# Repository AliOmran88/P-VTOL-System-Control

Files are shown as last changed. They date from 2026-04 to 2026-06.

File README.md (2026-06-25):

# P-VTOL Control System

A 1-DOF Planar Vertical Take-Off and Landing (P-VTOL) platform developed for studying system modeling, state-feedback control, embedded systems, and real-time communication between Arduino and LabVIEW.

The project demonstrates the complete workflow from mechanical design and fabrication to controller implementation and experimental validation on a physical system.

---

## Project Overview

The objective of this project is to stabilize and control the angular position of a rotating beam actuated by two BLDC motors.

The project is divided into the following stages:

1. Mechanical Design
2. Mathematical Modeling
3. Sensor Measurement and State Estimation
4. State-Feedback Controller Design
5. Arduino Implementation
6. LabVIEW Monitoring and Analysis
7. Real-Time Communication using NI-VISA
8. Experimental Validation

---

# Mechanical Design

The mechanical structure was designed using SolidWorks and fabricated using 3D printing.

Main components include:

* Main Beam
* Motor Holders
* Bearing Supports
* Sensor Mounts
* Bearing Retainers
* Teflon Base Plate
* 6201 Bearings
* Flexible Shaft Coupling

### CAD Model

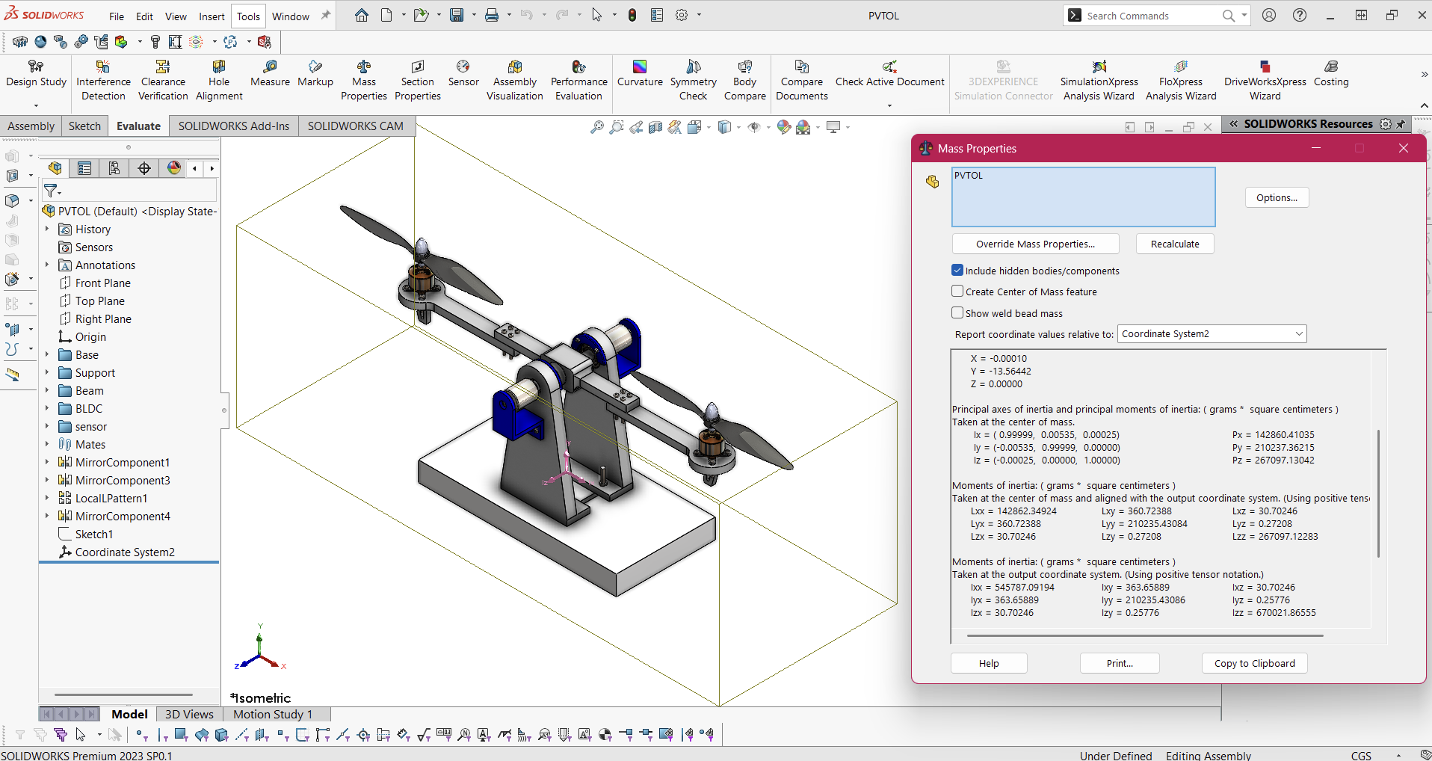
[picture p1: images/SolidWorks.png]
CAD Model


### Final Assembly

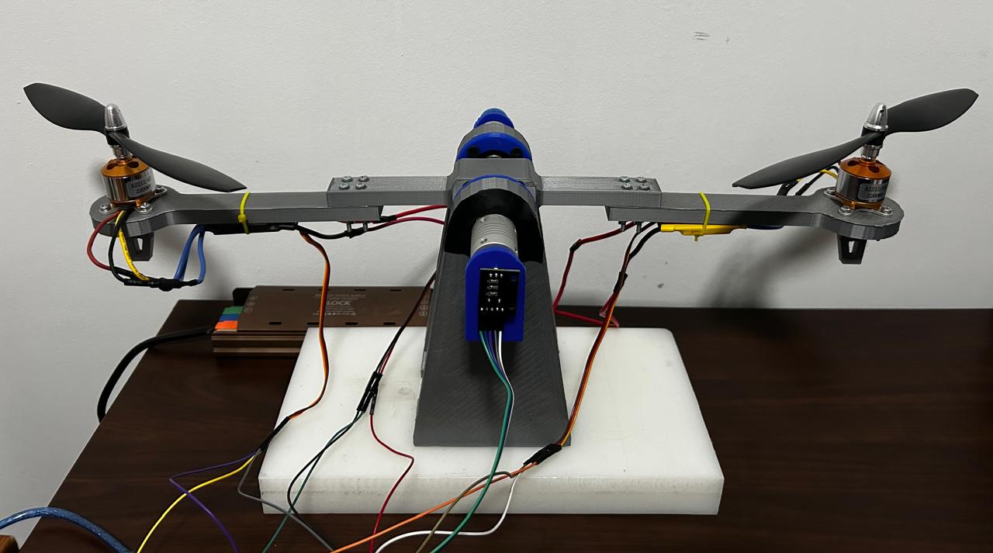
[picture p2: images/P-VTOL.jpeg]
PVTOL System


---

# Mathematical Modeling

The system is modeled as a rigid beam rotating about a fixed pivot.

Differential thrust generated by the two BLDC motors produces the control torque acting on the beam.

The resulting equation of motion is:

```text id="9ktgx0"
Jθ̈ + bθ̇ = u
```

where:

* J : Moment of inertia
* b : Damping coefficient
* θ : Angular position
* u : Control input

The model is converted into state-space form and used for controller design and analysis.

### Free Body Diagram

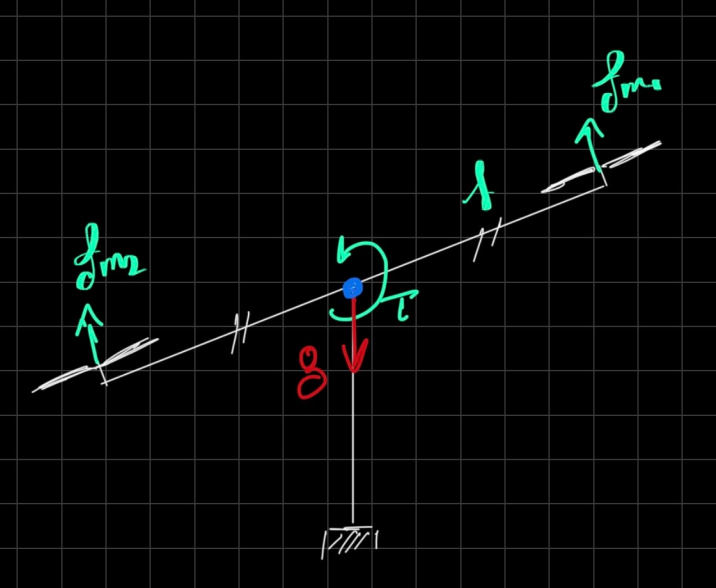
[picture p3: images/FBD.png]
Free Body Diagram


---

# Measurement and State Estimation

An MPU6050 IMU is mounted near the pivot point to estimate the system states.

Measured quantities:

* Angular Position (θ)
* Angular Velocity (ω)

The accelerometer is used to estimate beam angle, while the gyroscope provides angular velocity measurements.

To improve estimation accuracy, a complementary filter is implemented to combine accelerometer and gyroscope measurements.

---

# Control System Design

A state-feedback controller is used to stabilize the system and track reference angles.

The implemented control law is:

```text id="cwsg5z"
du = -(Kθ(θ - θref) + Kωω)
```

where:

* Kθ : Position gain
* Kω : Velocity gain
* θref : Desired angle

The controller uses:

* Angle error for position correction
* Angular velocity feedback for damping

Additional implementation features include:

* PWM Saturation
* Slew-Rate Limiting
* Reference Tracking

### System Block Diagram

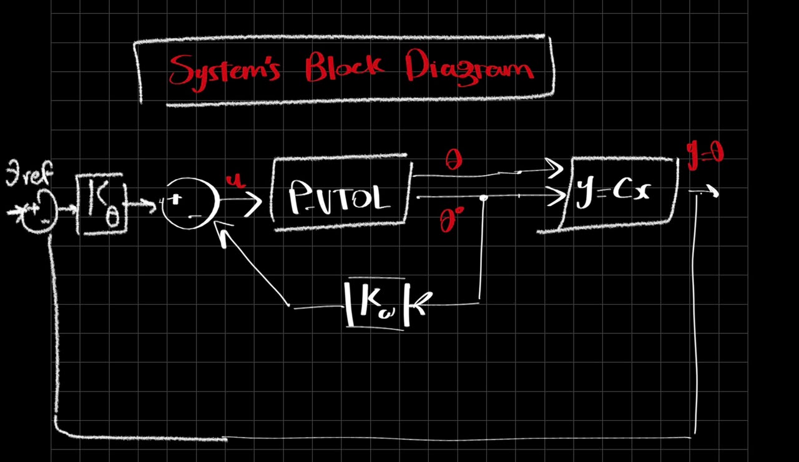
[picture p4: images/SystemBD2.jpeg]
System Block Diagram


---

# Controller Implementation

The complete controller implementation is located inside the **Controller** directory.

```text id="c49h7k"
Controller/
├── RootLocusSF.vi
├── UI_VISA.vi
├── SF_Servo.vi
└── SF_Control/
    └── SF_Control.ino
```

---

## RootLocusSF.vi

This LabVIEW VI was developed for controller design and system analysis.

Functions:

* Enter system parameters
* Construct the state-space model
* Analyze open-loop dynamics
* Calculate state-feedback gains
* Plot root locus
* Compare system response before and after control

This VI was used to determine suitable controller gains before implementing them on the physical system.

### Dynamic Analysis VI

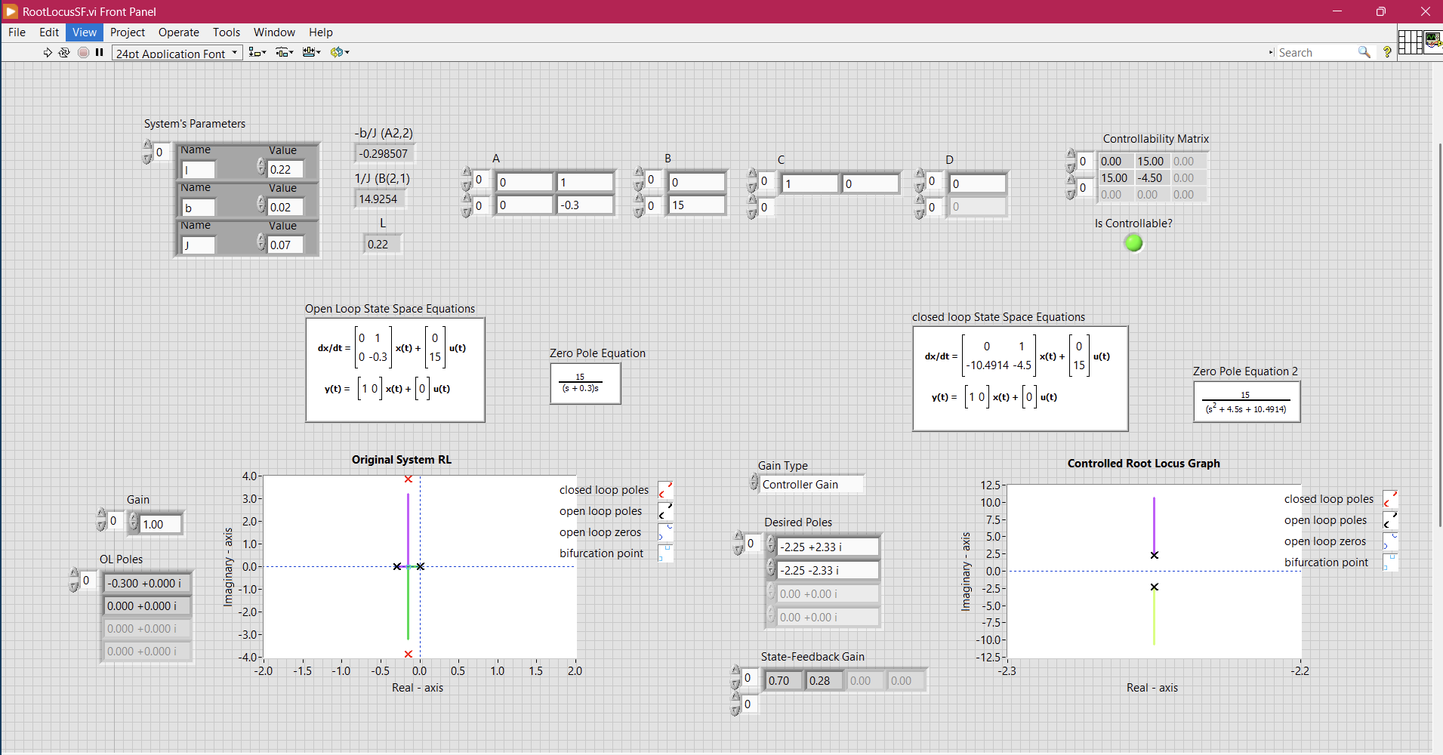
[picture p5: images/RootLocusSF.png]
LabVIEW Analysis


### Access File

[Open RootLocusSF.vi](Controller/RootLocusSF.vi)

---

## SF_Servo.vi

This LabVIEW VI was developed for simulating tracking problem of the system (as it is type 1, with integrator).

### Tracking Problem Simulation VI

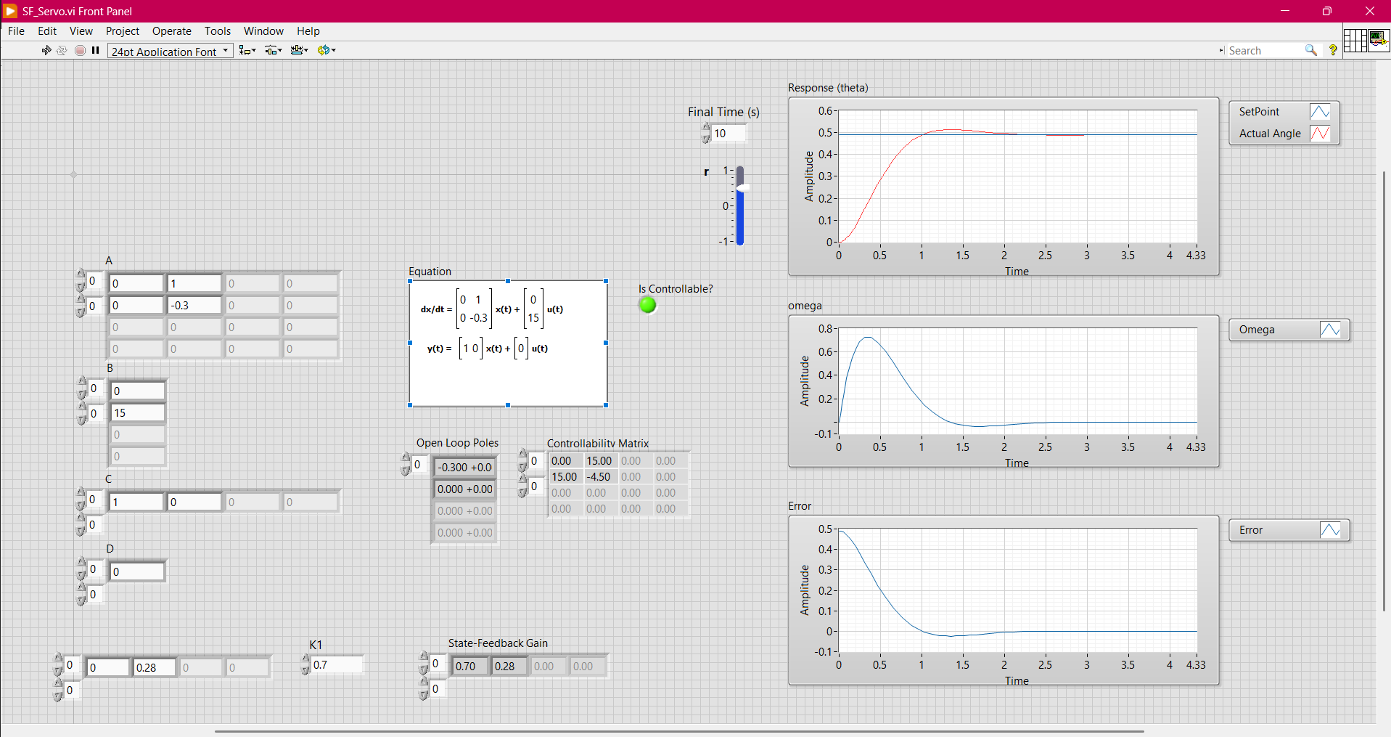
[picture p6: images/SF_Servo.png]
Tracking Simulation

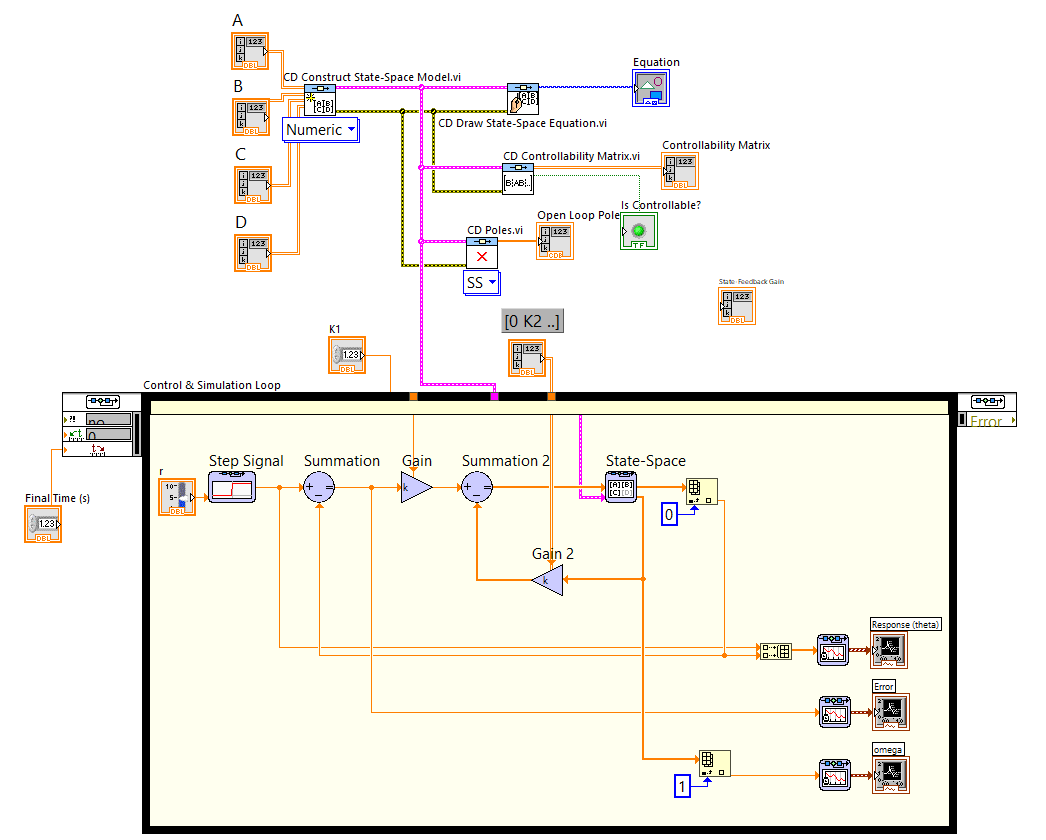
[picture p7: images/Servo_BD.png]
Block Diagram


### Access File

[Open SF_Servo.vi](Controller/SF_Servo.vi)

---

## SF_Control.ino

This Arduino program implements the real-time controller.

Responsibilities:

* Read MPU6050 measurements
* Estimate angle and angular velocity
* Execute the state-feedback control law
* Generate ESC commands
* Apply PWM saturation and slew-rate limiting
* Send measurements and control signals to LabVIEW
* Receive controller gains and reference angle from LabVIEW

The Arduino serves as the embedded controller responsible for executing the control loop in real time.

### Access File

[Open SF_Control.ino](Controller/SF_Control/SF_Control.ino)

---

## UI_VISA.vi

This LabVIEW VI provides the user interface used during experiments.

Functions:

* Send reference angle (θref)
* Send controller gains (Kθ and Kω)
* Receive system measurements
* Receive motor commands
* Plot real-time data
* Monitor system performance
* Tune controller parameters online

This allows controller gains and setpoints to be modified during operation without reprogramming the Arduino.

### User Interface

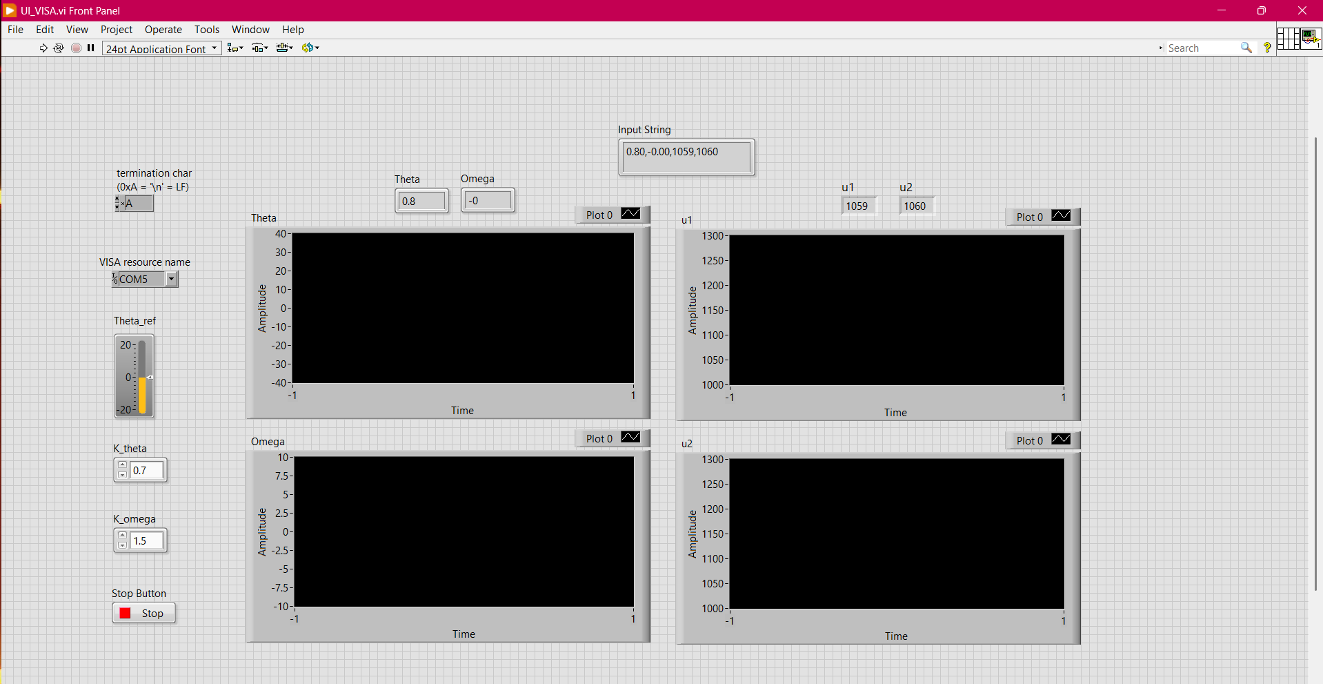
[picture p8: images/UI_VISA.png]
LabVIEW Interface


### Access File

[Open UI_VISA.vi](Controller/UI_VISA.vi)

---

# Serial Communication Using NI-VISA

Communication between Arduino and LabVIEW is achieved through NI-VISA serial communication.

### Data Sent from LabVIEW

* Reference Angle (θref)
* Position Gain (Kθ)
* Velocity Gain (Kω)

### Data Sent from Arduino

* Angular Position (θ)
* Angular Velocity (ω)
* Motor Command u1
* Motor Command u2

This bidirectional communication enables real-time monitoring, controller tuning, and experimental validation.

---

# Experimental Results

The state-feedback controller successfully stabilizes the beam and tracks reference angles in real time.

During operation:

1. LabVIEW sends controller gains and desired setpoints.
2. Arduino executes the control algorithm.
3. Sensor measurements are acquired and processed.
4. Control commands are sent to the motors.
5. System states and actuator commands are streamed back to LabVIEW for visualization and analysis.

The complete experimental demonstration is available below.

### Demonstration Video

[Watch Project Demonstration](Videos/testExp.mp4)

---

# Repository Structure

```text id="t9nqmg"
├── Controller/
│   ├── RootLocusSF.vi
│   ├── UI_VISA.vi
│   └── SF_Control/
│       └── SF_Control.ino
│
├── images/
│
├── Videos/
│
├── CAD/
│
├── STL/
│
├── Docs/
│
└── README.md
```

---

# Future Improvements

Possible extensions of this project include:

* LQR Control
* LQG Control
* Kalman Filtering
* Fuzzy Logic Control
* Model Predictive Control (MPC)
* Vision-Based Feedback
* Adaptive Control

---

# Author

**Ali Gamal Ali**

Mail: 
ali.gamal@ejust.edu.eg

LinkedIn:
https://www.linkedin.com/in/ali-gamal

GitHub:
https://github.com/AliOmran88

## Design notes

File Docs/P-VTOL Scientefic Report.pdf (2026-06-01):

## P-VTOL Control System Project Guide

Ali Gamal Ali

## Introduction

This document serves as a practical guide for students working on the P-VTOL (Planar Vertical Take-Off and Landing) project.

The goal of the project is to design, model, control, and experimentally validate a one degree-offreedom (1-DOF) aerial platform actuated by two brushless DC (BLDC) motors.

## Mechanical Design

The project started with the design of a lightweight structure capable of rotating around a fixed pivot, parts stated below:

| Main beam
| Motor Holder (×2)
| Bearing Supports (×2)
| Sensor Mount (×2)
| Bearing Retainer (×2)
| Base (Material: Teflon, Dimensions: 30 × 15 × 3 cm, Fabrication: CNC Machining)

The CAD model was developed using SolidWorks, as shown in Figure 1.

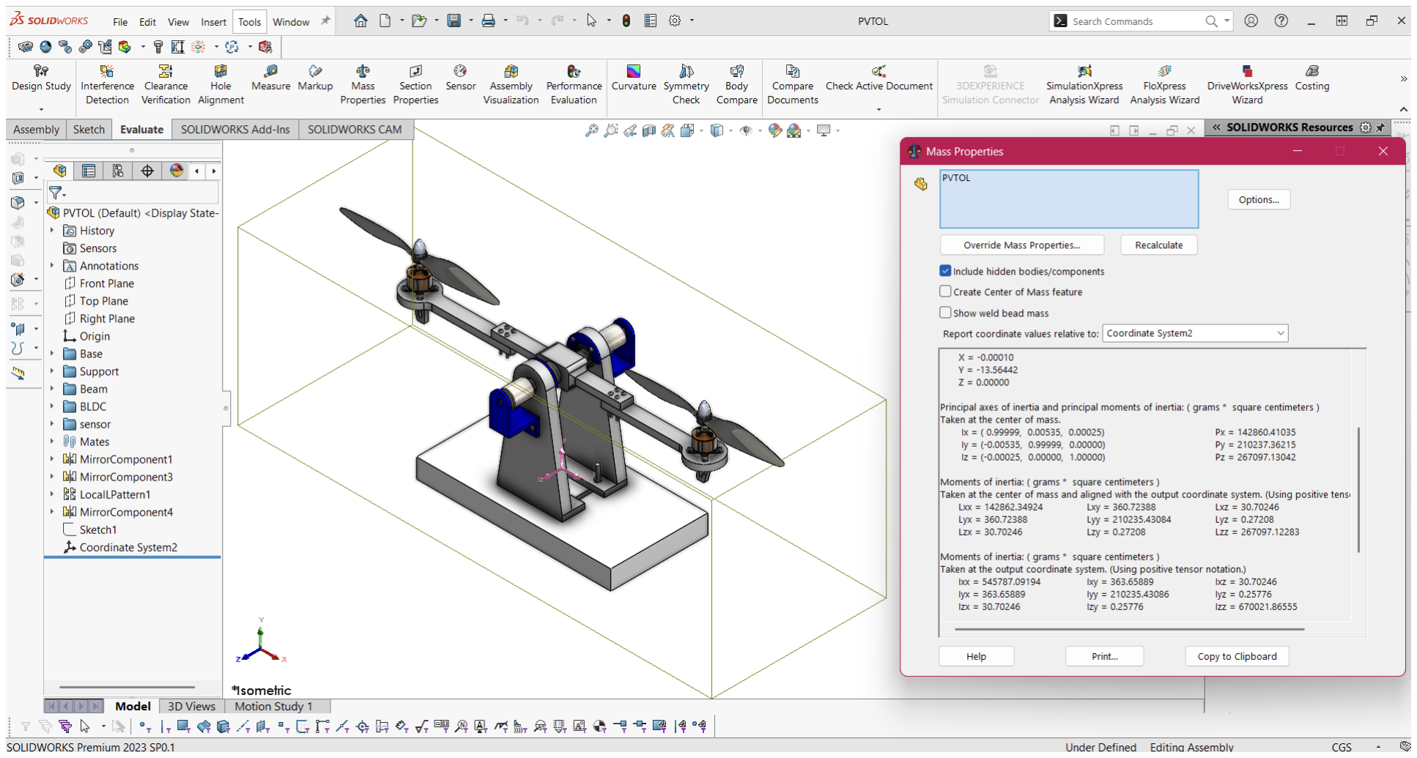
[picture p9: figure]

Figure 1: SolidWorks CAD Assembly Model

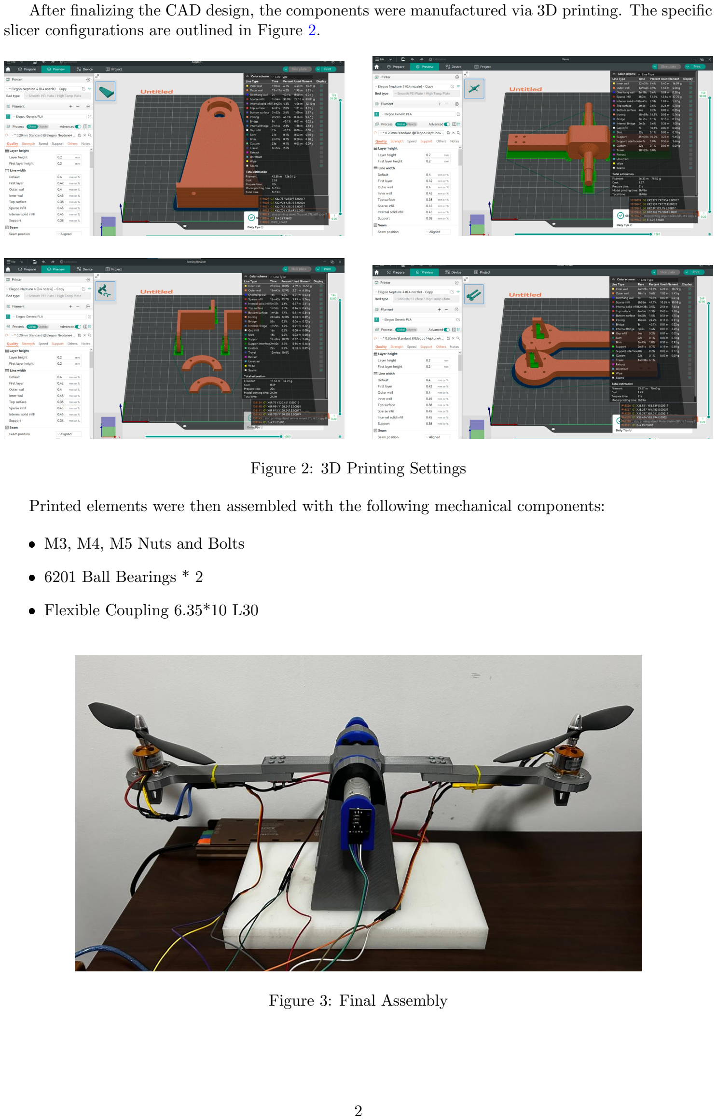
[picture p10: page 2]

After finalizing the CAD design, the components were manufactured via 3D printing. The specific slicer configurations are outlined in Figure 2.

Figure 2: 3D Printing Settings

Printed elements were then assembled with the following mechanical components:

| M3, M4, M5 Nuts and Bolts
| 6201 Ball Bearings * 2
| Flexible Coupling 6.35*10 L30

Figure 3: Final Assembly

## Mathematical Modeling

The P-VTOL platform can be modeled as a rigid beam rotating about a fixed pivot. The angular position of the beam is denoted by θ.

Free Body Diagram

Figure 4 illustrates the free body diagram of the system.


Figure 4: Free body diagram of the P-VTOL system

The control torque is generated by the differential thrust of the two motors,

τ = l(FR − FL)

where l is the distance from the pivot to each motor.
To account for friction and aerodynamic losses, a viscous damping torque is included,

τd = b

˙θ

where b is the damping coefficient.

Euler-Lagrange Formulation

The kinetic energy of the system is

T =

1
2

J ˙θ
2

where J is the moment of inertia about the pivot axis.
Since the beam is balanced around the pivot, the variation in potential energy is negligible,

V = 0

Therefore, the Lagrangian becomes

L = T − V =

1
2

J ˙θ
2

Applying the Euler-Lagrange equation

d

dt
∂L
∂ ˙θ
−

∂L
∂θ = Q

Q = l(FR − FL) − b

˙θ

J ¨θ + b

˙θ = l(FR − FL)

u = l(FR − FL)

the equation of motion becomes

J ¨θ + b

˙θ = u

## State-Space Model

For controller design, the states are chosen as

x1 = θ, x2 = ˙θ

The state equations become

x˙ 1 = x2

x˙ 2 = −

b
J

x2 +

1
J

u

which can be written in matrix form as

x˙ = Ax + Bu

where

A =

"
0 1

0 −

b
J
, B =

"
0
1
J

The output vector is selected as

y = Cx + Du

with

C =

1 0

0 1
, D =
0
0

“‘

## Measurements

The MPU6050 sensor was used to measure angle and angular velocity, The sensor was mounted on top of the beam center near the pivot point.

Angle Measurement

The accelerometer angle (Pitch Angle) was computed using

θacc = tan⁻¹

Ax
Az
∗ 180/π

Ax = g cos θ Az = g sin θ

Schematic for this equation is shown in Figure 5.

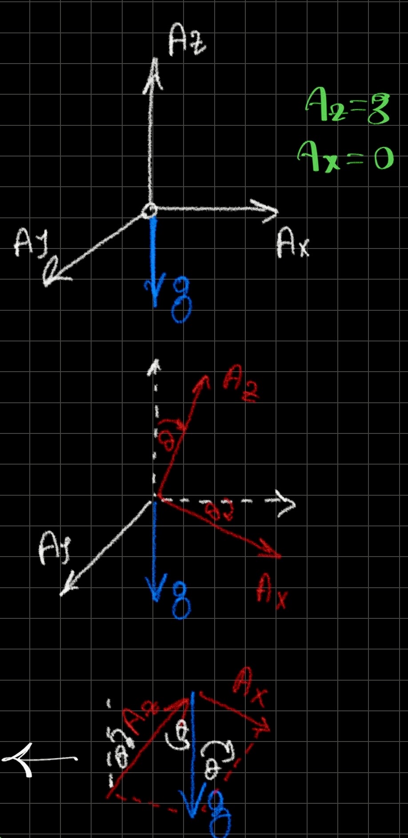
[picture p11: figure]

Figure 5: Obtaining Pitch Angle from Accelerometer

Angle Calibration

Measure angle at startup θref then subtract it as in the equation below, this is to ensure that angle measured is calibrated at zero.

θ = θacc − θref

Angular Velocity Measurement

Angular velocity is defined as the rate of change of angular position over time:

ω =

∆θp
∆t

(rad/s)

For the specific gyroscope sensor used, the sensitivity scale factor is given as 131 LSB = 1◦/s. Therefore, the raw gyroscope reading in the y-axis (Gy) can be converted to degrees per second using:

ωdeg/s =

Gy
131
To ensure measurements are free from zero-rate drift or offset errors, a calibration value (G0 or Goff) must be measured while the sensor is completely at rest. Subtracting this offset yields the corrected angular velocity in degrees per second:

ω =

Gy − G0
131
To convert this corrected measurement into radians per second (rad/s), multiply it by π
180 :

ωrad/s =

Gy − Goff

131
×

π
180

Angle Estimation and Sensor Fusion

Gyroscope Integration

The angular position θ can be measured by integrating the angular velocity ω over a time step dt using Euler’s method:
θi+1 = θi + ω · dt

Complementary Filter

To overcome individual sensor limitations, a complementary filter is implemented. It accounts for the low-frequency drift inherent in gyroscope integration while mitigating the high-frequency noise of the accelerometer data (θacc):
θ = α · (θ + ω · dt) + (1 − α) · θacc

Where α is a tuning constant, typically chosen to be around 0.98.

## System Parameters

The physical parameters of the system are defined as

l = 22 cm = 0.22 m

b = 0.02 N · m · s/rad, J = 0.067 kg · m² (Obtained from SolidWorks)

## State-Space Model

Substituting the system parameters into the state-space equations yields the system matrices

A =

0 1
0 −0.3
, B =
0

15

The output and direct transmission matrices are selected as

C =

1 0

0 1
, D =
0

## Control System Design

The characteristic equation of the system is determined by

Ch. eqn. =⇒ det(sI − A) = 0

Evaluating the determinant of the state matrix gives

s −1
0 s + 0.3

= s(s + 0.3) = 0

Solving for the roots yields the open-loop poles of the system at

s = 0, s = −0.3

## Controllability Analysis

The controllability matrix M is constructed as

M =

B AB
=
0 15

15 −45

Evaluating the rank of the matrix yields

Rank(M) = 2 ”Controllable”

The system is not in controllable canonical form, as second row of B is not 1;

## State-Feedback Control

The state-feedback control law is defined as

u = −Kx = −

K1 K2

x1
x2

Expressing this in terms of physical parameters θ and ˙θ gives

u = −Kθθ − Kω

˙θ

The closed-loop state equation is governed by

x˙ = (A − BK)x

Substituting the state matrix A, input matrix B, and gain vector K yields
0 1
0 −0.3
−
0

15

Kθ Kω

=

0 1
0 −0.3
−
0 | 0
15Kθ | 15Kω

Consequently, the closed-loop system matrix A˜ is obtained as

A˜ =

0 | 1
−15Kθ | −0.3 − 15Kω

## Closed-Loop Pole Placement

The characteristic equation of the closed-loop system is analyzed to determine the closed-loop poles

det(sI − A˜) = 0

Substituting the identity matrix I and the closed-loop system matrix A˜ gives

s 0
0 s
−
0 | 1
−15Kθ | −0.3 − 15Kω

= 0

Simplifying the matrix subtraction within the determinant yields

s | −1
15Kθ | s + 0.3 + 15Kω

= 0

Computing the determinant results in the following polynomial expression

s(s + 0.3 + 15Kω) + 15Kθ = 0

Expanding and grouping the terms by powers of s yields

s

2 + 0.3s + 15Kωs + 15Kθ = 0

s

2 + (0.3 + 15Kω)s + 15Kθ = 0

## Controller Gain Calculation

The actual closed-loop characteristic equation is compared against the standard second-order system design template

s

2 + 2ζωns + ω

2
n = 0

The desired transient performance characteristics are specified as

ζ = 0.7, ωn = 3.24

These parameters correspond to the desired closed-loop pole locations at

s1,2 = −2.25 ± 2.33i

Equating the coefficients of the standard equation to the system’s characteristic equation yields the design formulas

2ζωn = 0.3 + 15Kω

ω

2
n = 15Kθ

Solving this system of equations for the state-feedback gains gives

Kθ = 0.7, Kω = 0.2824

## Experimental Tuning

While the analytical design gives precise theoretical values, physical constraints or unmodeled dynamics often require empirical adjustment.
Comparing the calculated gains against experimental testing yields
Kθ = 0.7, | Kω = 0.2824
Experimentally, Kθ = 0.7, | Kω = 1.5 =⇒ Best Response

## Implementation of the Control Law

Regulator Implementation

For regulation tasks where the primary goal is to drive the system states to zero (θ = 0), the implementation of the state-feedback control law is given by

State-Feedback Control Law =⇒ u = −0.7θ − 0.2824 ˙θ

Regulator: θ = 0

Tracking Implementation

To extend the controller for reference tracking applications, the control law is adjusted to operate on the tracking error vector by comparing the actual states to the desired reference angle

For Tracking =⇒ u = −

Kθ Kω

θ − θref
˙θ

where the reference is set as desired

## Actuation

Differential Control

The base throttle value is established at a baseline level, with differential control applied symmetrically to the actuators:

Base Throttle =⇒ u0 = 1100

u1 = u0 + du

u2 = u0 − du

Slew-Rate Limiting

To preserve actuator longevity and system stability, the change in the pulse-width modulation (PWM) signal per execution step is bounded:

|∆PWM| ≤ Max. allowed Step

where ∆PWM represents the changes ∆u1 and ∆u2. This functions as a:

Limiting Step to avoid sudden spikes in PWM

Saturation

The final control output commands are hard-clipped within physical operating limits:

Saturation Boundary =⇒ [1000, 1300]

State-Feedback Integration

The differential control effort du is derived via the state-feedback tracking law, balancing correction and physical damping:

du = − (Kθ × (θ − θref) + Kω × xω)

where the component terms are allocated to specific control actions:

Kθ × (θ − θref) =⇒ Corrects angle

Kω × xω =⇒ Damps motion

System’s Block Diagram

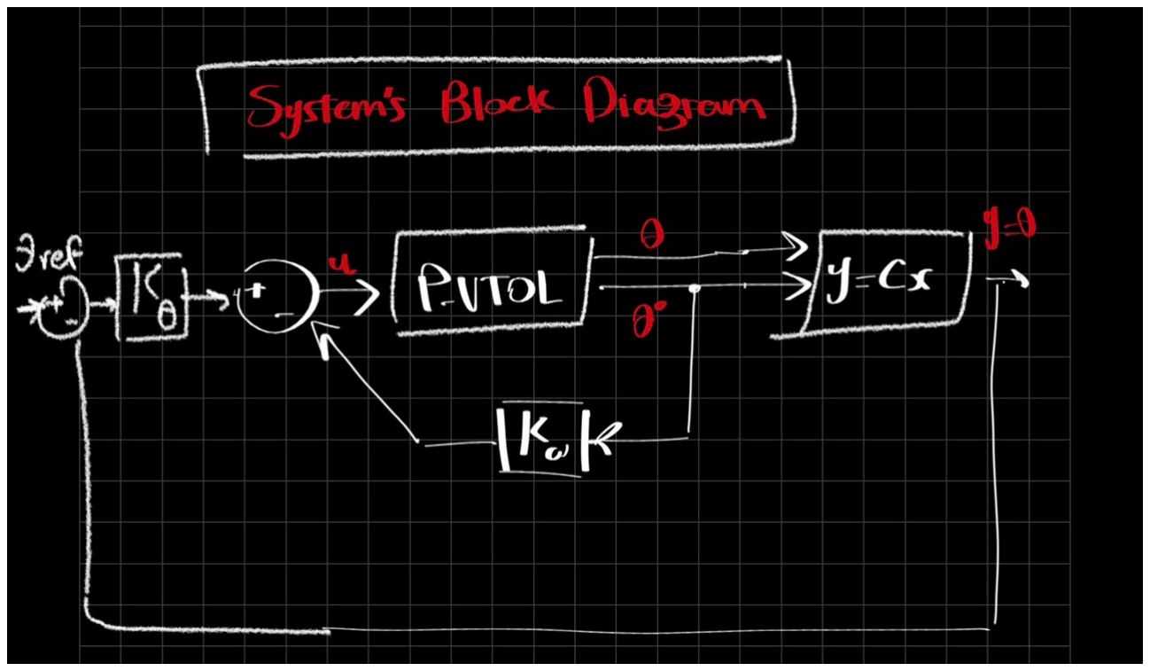
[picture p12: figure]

Figure 6: System’s Block Diagram

## labView Control Design

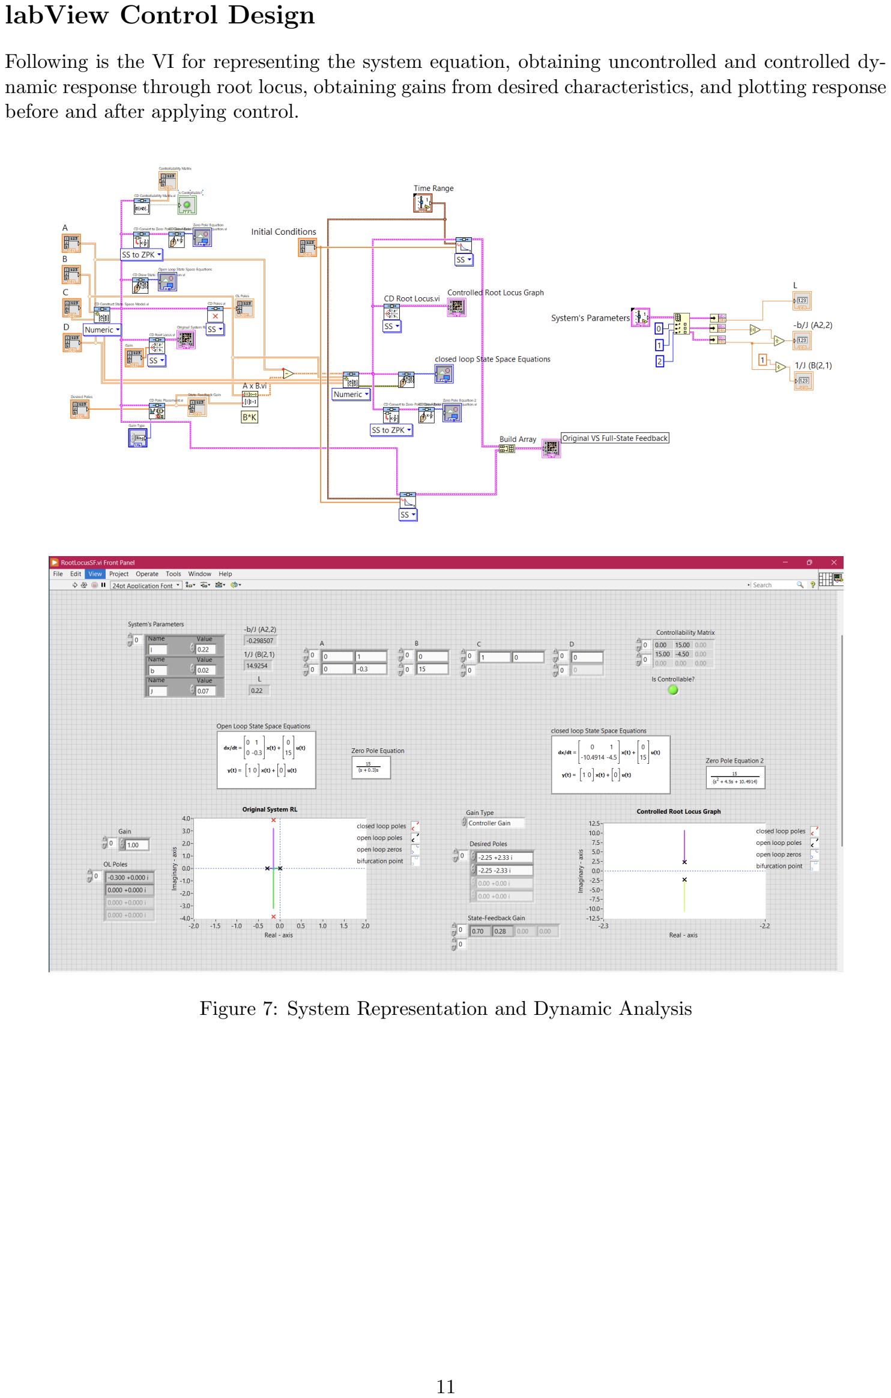
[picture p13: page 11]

Following is the VI for representing the system equation, obtaining uncontrolled and controlled dynamic response through root locus, obtaining gains from desired characteristics, and plotting response before and after applying control.

Figure 7: System Representation and Dynamic Analysis

## Data Acquisition and Communication Interface

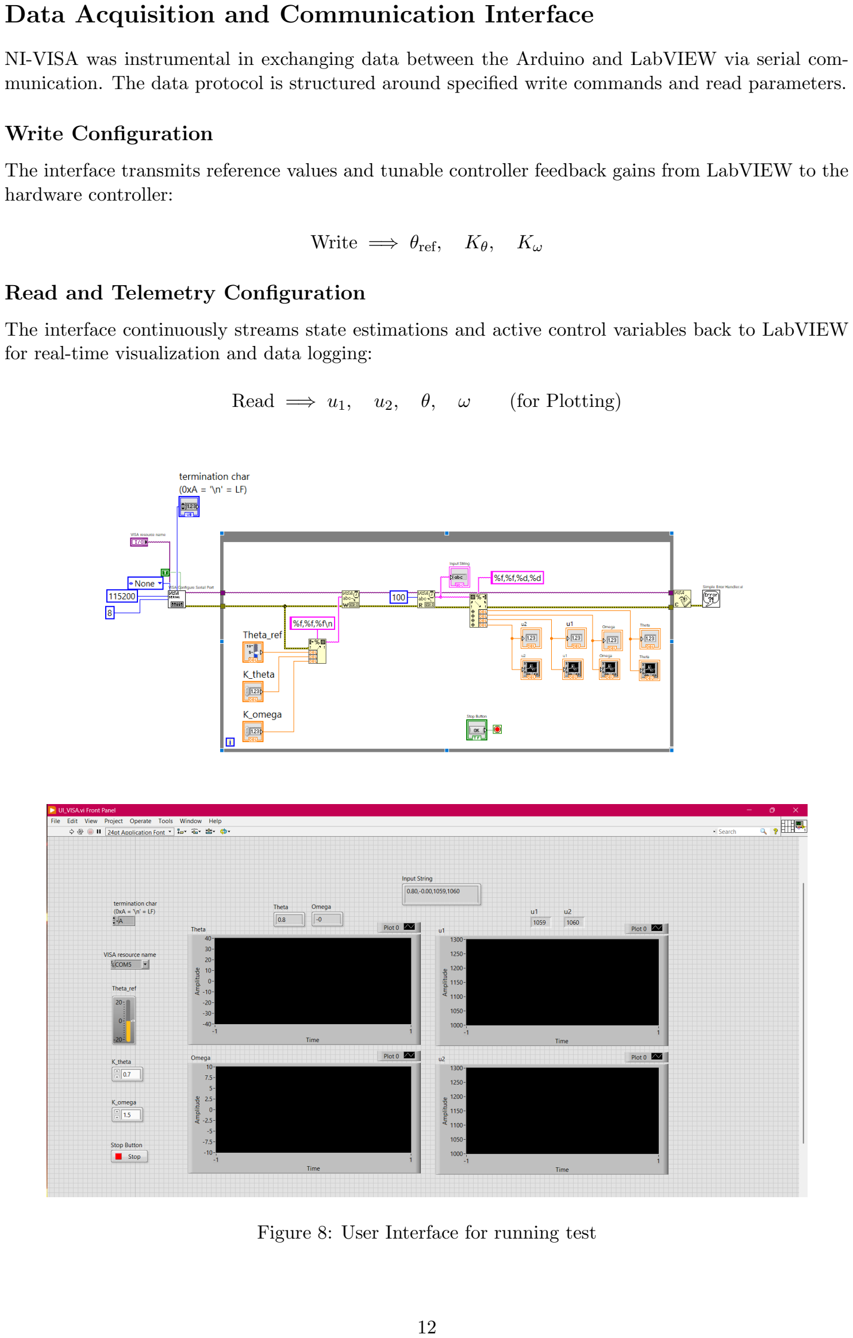
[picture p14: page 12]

NI-VISA was instrumental in exchanging data between the Arduino and LabVIEW via serial communication. The data protocol is structured around specified write commands and read parameters.

Write Configuration

The interface transmits reference values and tunable controller feedback gains from LabVIEW to the hardware controller:

Write =⇒ θref, | Kθ, | Kω

Read and Telemetry Configuration

The interface continuously streams state estimations and active control variables back to LabVIEW for real-time visualization and data logging:

Read =⇒ u1, | u2, | θ, | ω | (for Plotting)

Figure 8: User Interface for running test

## Experimental Results

After completing the implementation, we conducted several experiments to test the system. The state-feedback controller successfully stabilized the beam and held it at the desired equilibrium position. During the tests, LabVIEW and the Arduino worked together in real time. LabVIEW sent the target angles and controller gains down to the Arduino. The Arduino then processed the sensor measurements, ran the control loop, adjusted the motors, and streamed the updated states and actuator efforts back to LabVIEW. This continuous data loop ran smoothly until a stop was requested. The successful balancing performance and real-time tracking are fully captured in the attached experiment video. running experiment video

## Conclusion and Future Work

This project demonstrated the complete development of a P-VTOL control system starting from mechanical design and ending with real-time implementation.
Future students can extend this work by implementing:
| LQR and LQG control
| Kalman filtering for more accurate measurements
| Fuzzy Logic Control
| Model Predictive Control

## References

| “PVTOL Exact Linearization Control,” IEEE Transactions on Automatic Control, for under- lying plant modeling mechanics.
| “Arduino-Based Embedded Systems Interfacing, Simulation, and LabVIEW GUI,” for structural insights regarding VISA buffer configurations.
| “MPU-6050 6-Axis Accelerometer/Gyroscope Datasheet,” InvenSense Inc., detailing calibration constants and LSB scaling ratios.
| “1-DOF Helicopter Stabilization Project Template Guide,” Acknowledgable work done by a colleague, preceding semester.

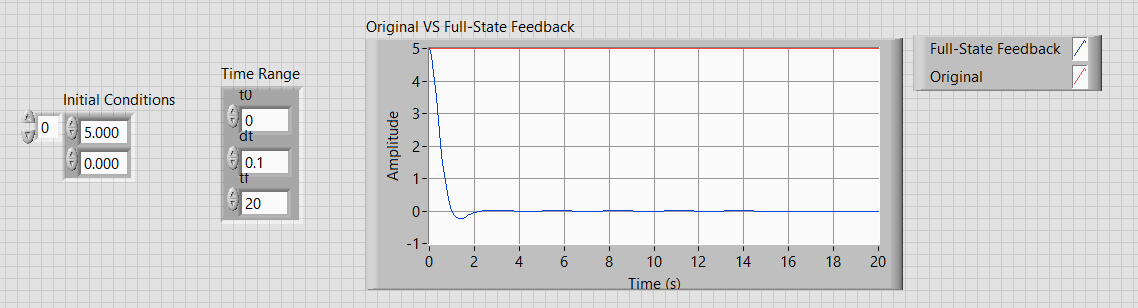
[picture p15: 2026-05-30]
images/RootLocusSF_Response.png

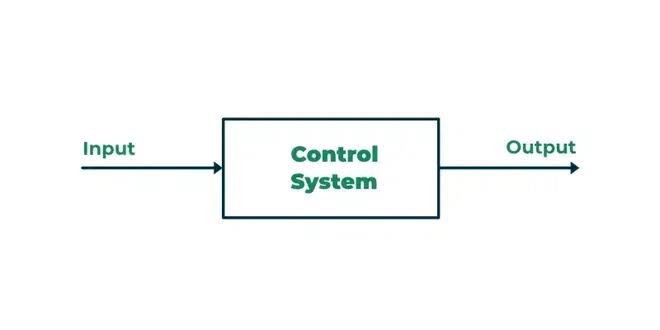
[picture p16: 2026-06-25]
images/cont.jpeg

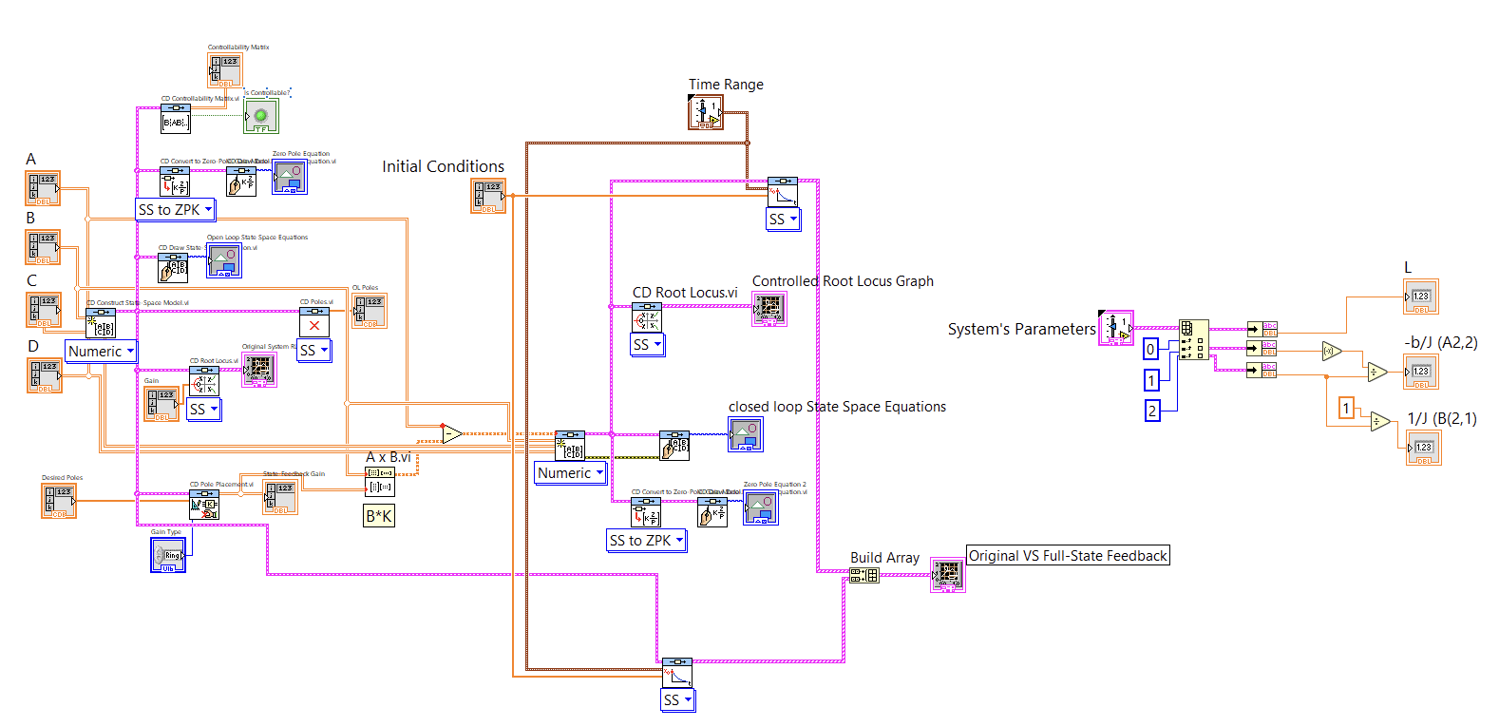
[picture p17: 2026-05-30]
images/RootLocusSF_BlockDiagram.png

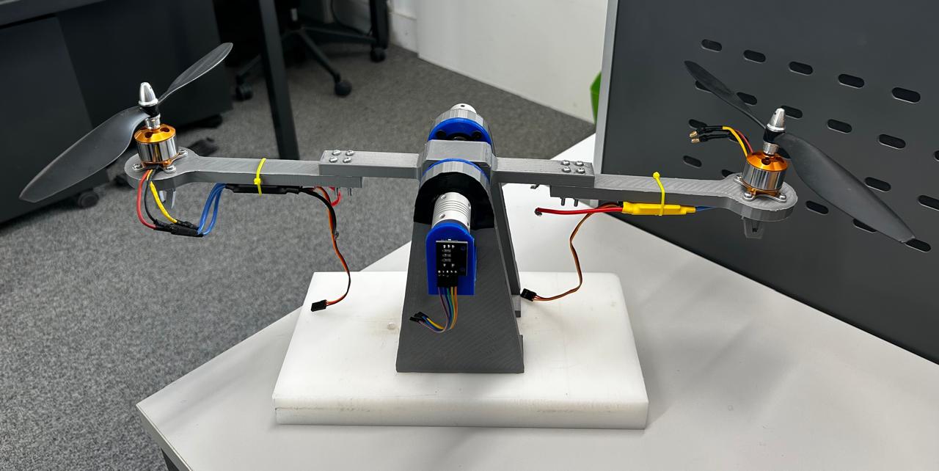
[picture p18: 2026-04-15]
images/PVTOL.jpeg

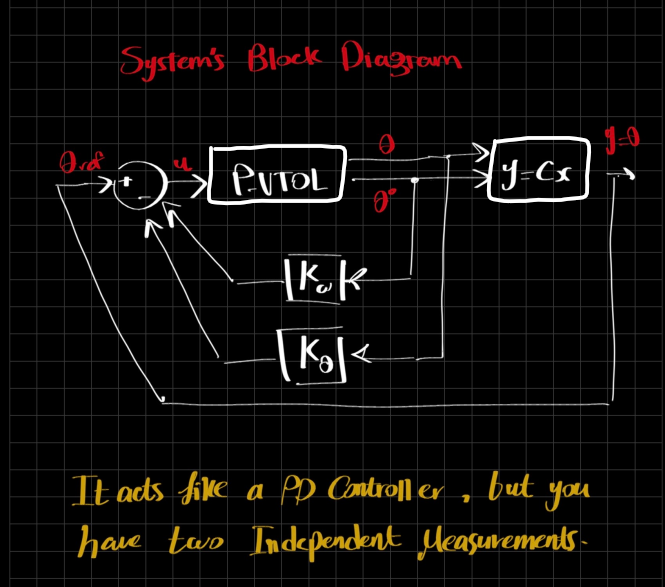
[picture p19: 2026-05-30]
images/SystemBD.png

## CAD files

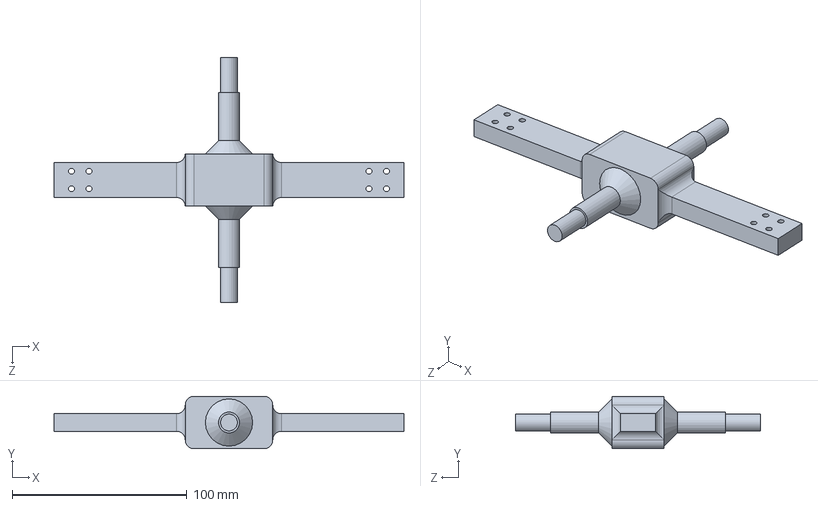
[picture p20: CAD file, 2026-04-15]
CAD/Beam.SLDPRT
200.0 x 30.0 x 140.0 mm

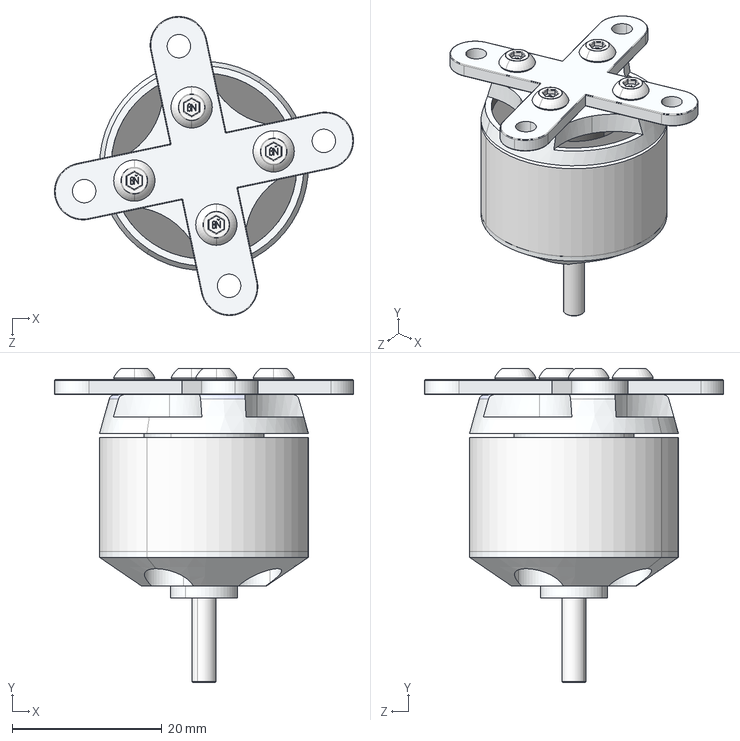
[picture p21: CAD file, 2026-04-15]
CAD/brushless-motor-bldc_2212-6t-2200kv-1.snapshot.1/Motor_BLDC_2212,6T_2200KV__With_Support.STEP
39.9 x 41.9 x 39.9 mm

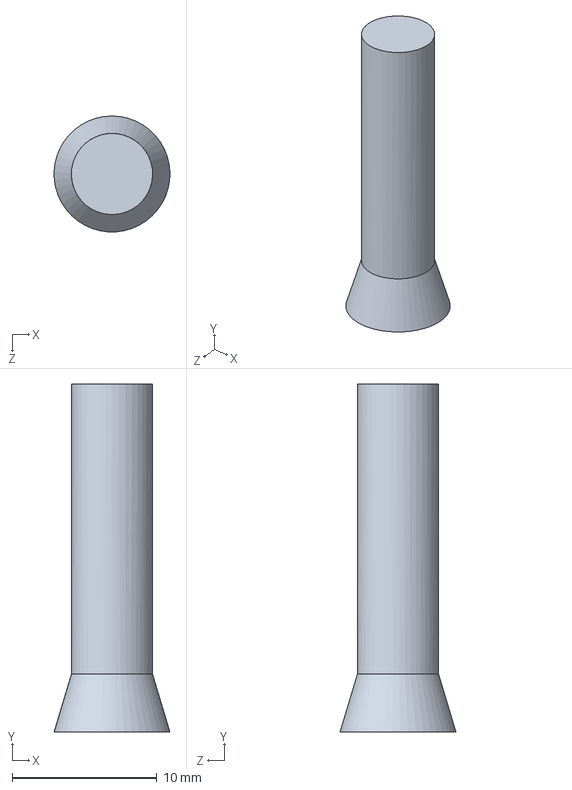
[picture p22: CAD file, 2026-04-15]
CAD/Propeller 10x45/1.SLDPRT
8.00 x 24.0 x 8.00 mm

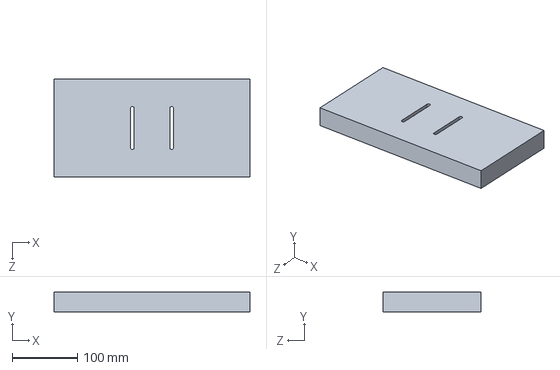
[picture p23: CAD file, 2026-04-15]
CAD/BasePlate.SLDPRT
300.0 x 30.0 x 150.0 mm

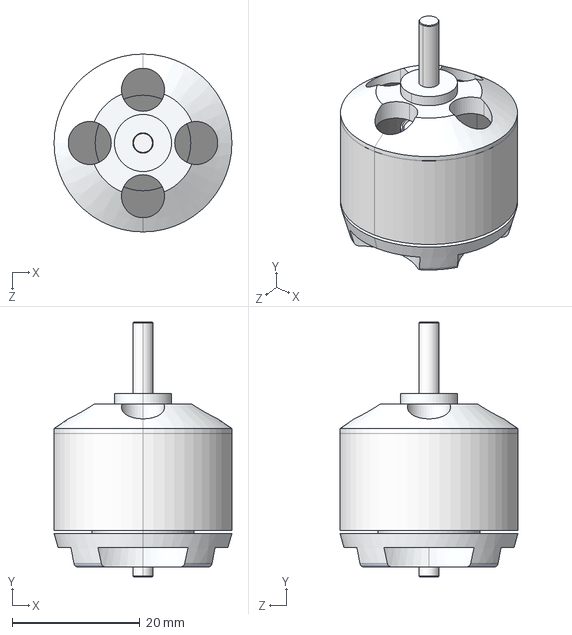
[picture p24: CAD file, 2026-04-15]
CAD/brushless-motor-bldc_2212-6t-2200kv-1.snapshot.1/Motor_BLDC_2212,6T_2200KV.STEP
27.9 x 40.0 x 27.9 mm

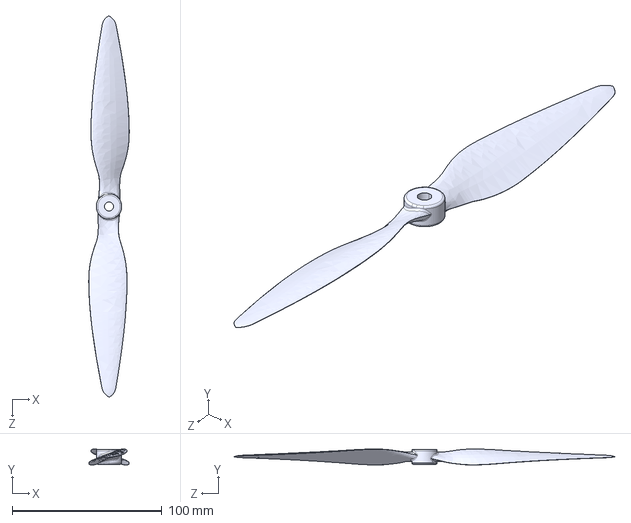
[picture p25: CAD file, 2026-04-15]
CAD/Propeller 10x45/Propeller 10x45.STEP
27.0 x 10.6 x 254.0 mm

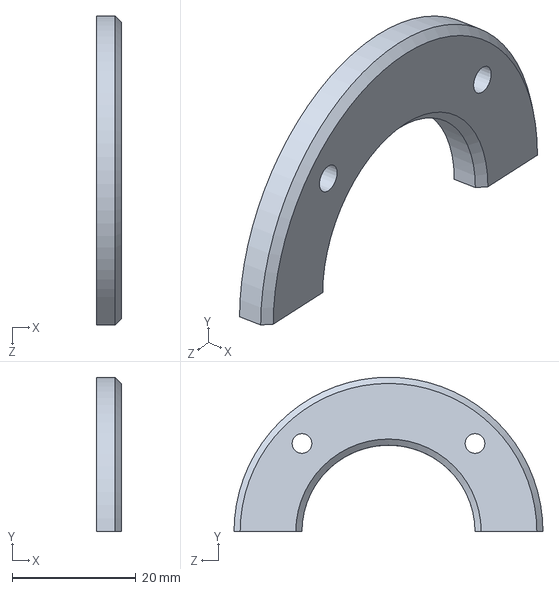
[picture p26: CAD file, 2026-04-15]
CAD/Bearing Retainer.SLDPRT
4.00 x 25.0 x 50.0 mm

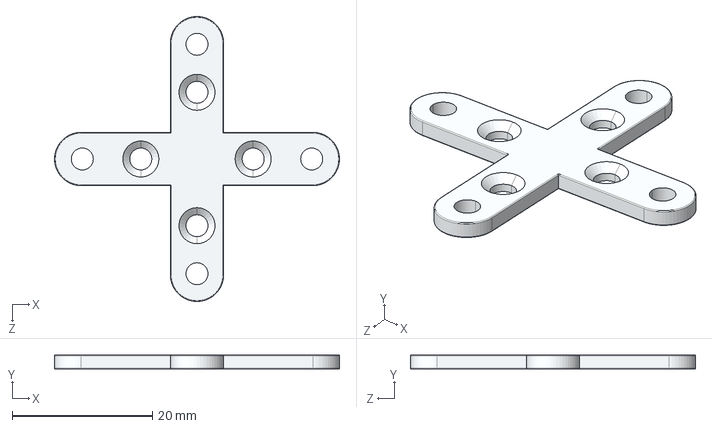
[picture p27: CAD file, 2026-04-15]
CAD/brushless-motor-bldc_2212-6t-2200kv-1.snapshot.1/Support_2MM_Al6061_2212.STEP
40.6 x 2.00 x 40.6 mm

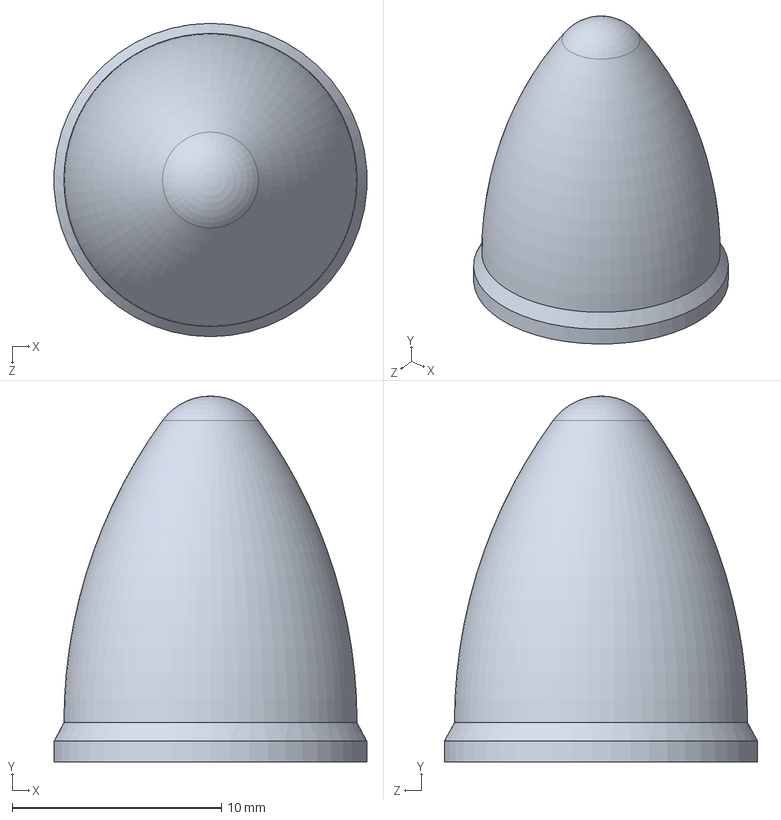
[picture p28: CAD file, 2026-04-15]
CAD/Propeller 10x45/2.SLDPRT
14.9 x 17.5 x 15.0 mm

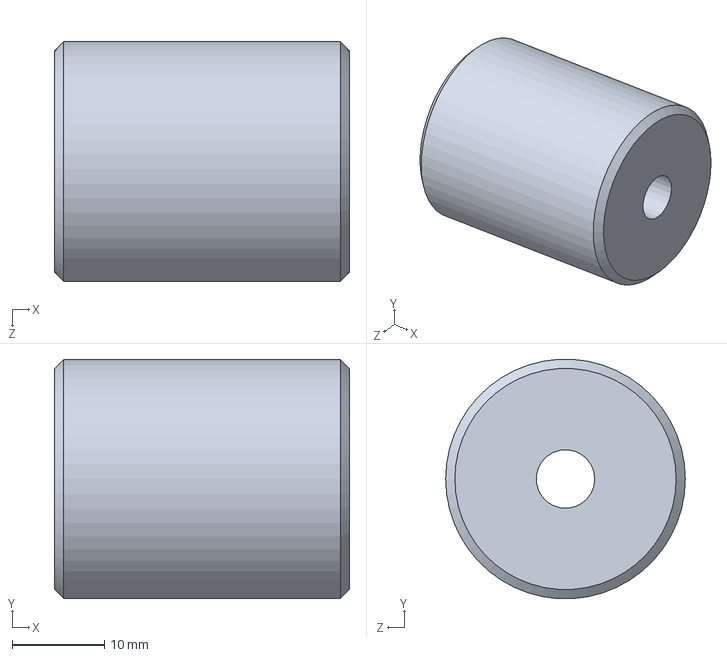
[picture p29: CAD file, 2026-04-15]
CAD/coupler.SLDPRT
32.0 x 25.9 x 26.0 mm

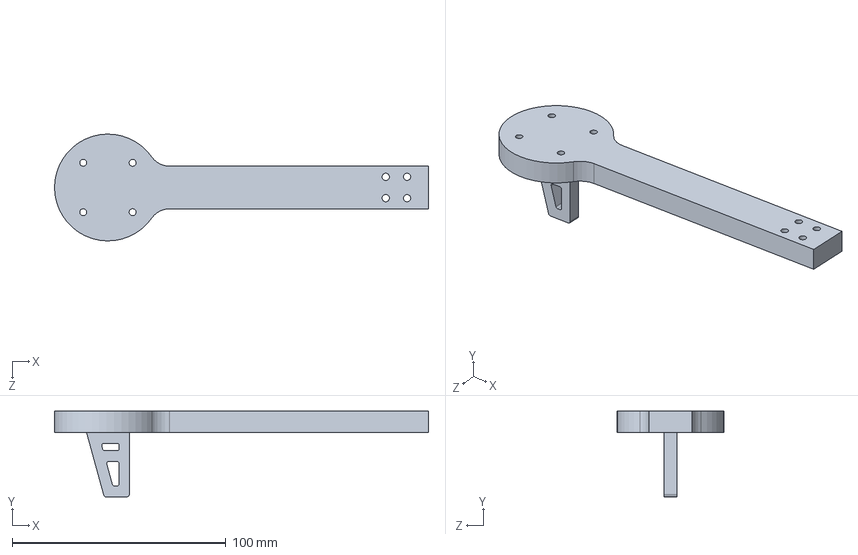
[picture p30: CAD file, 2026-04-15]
CAD/Motor Holder.SLDPRT
175.0 x 40.0 x 50.0 mm

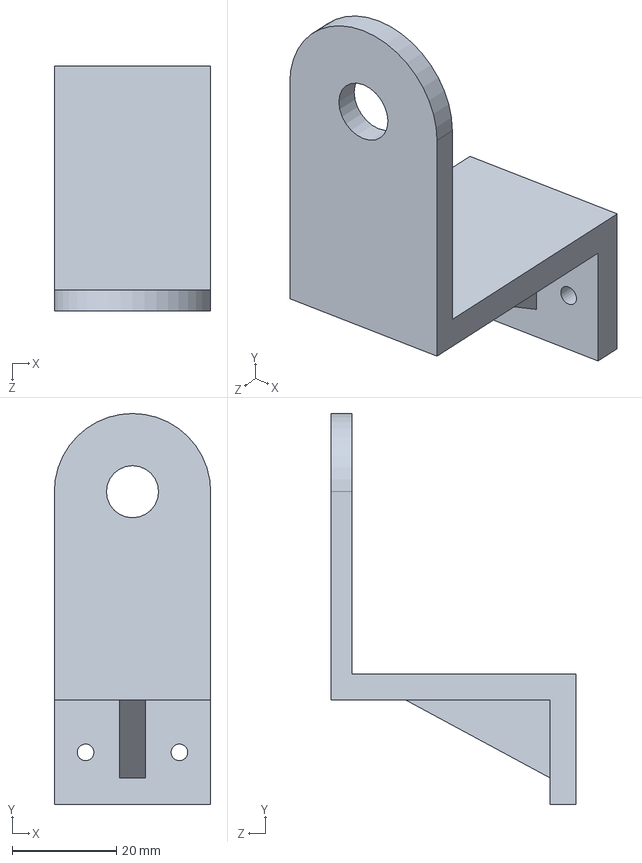
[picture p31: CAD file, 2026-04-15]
CAD/sensor mount.SLDPRT
30.0 x 75.0 x 47.0 mm

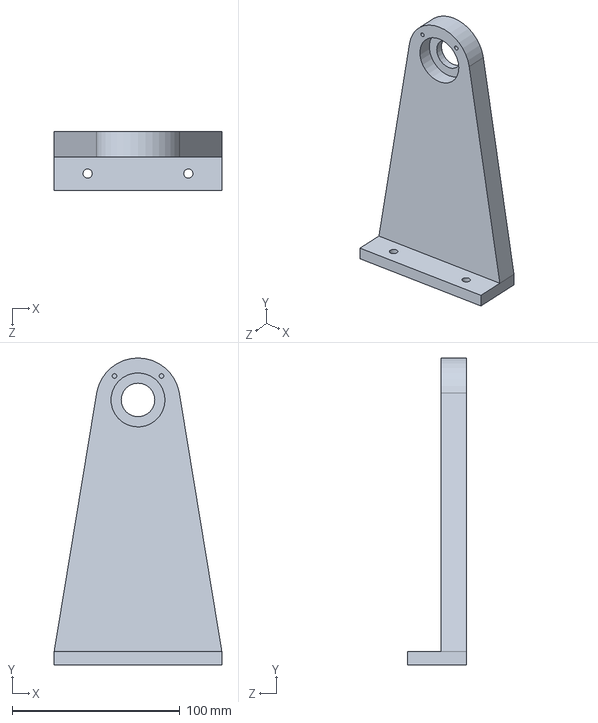
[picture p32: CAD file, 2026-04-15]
CAD/Support.SLDPRT
100.0 x 183.0 x 35.0 mm

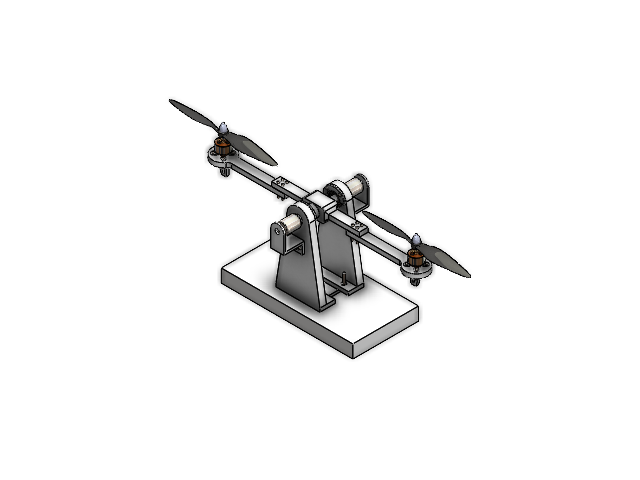
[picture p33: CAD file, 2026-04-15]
CAD/PVTOL.SLDASM
BasePlate
pan cross head_am x 20
hex nut jam_am x 4
Support x 2
Bearing Retainer x 2
radial ball bearing_68_din x 2
pan head tapping screw_am x 8
Beam
Motor Holder x 2
hex nut style 1_am x 16
Motor_BLDC_2212,6T_2200KV x 2
Support_2MM_Al6061_2212 x 2
Propeller 10x45 x 2
coupler x 2
sensor mount x 2

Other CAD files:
CAD/Propeller 10x45/Propeller 10x45.SLDPRT
CAD/basePlateDrw.SLDDRW
CAD/brushless-motor-bldc_2212-6t-2200kv-1.snapshot.1/Motor_BLDC_2212,6T_2200KV.IGS
CAD/brushless-motor-bldc_2212-6t-2200kv-1.snapshot.1/Motor_BLDC_2212,6T_2200KV.SLDPRT
CAD/brushless-motor-bldc_2212-6t-2200kv-1.snapshot.1/Motor_BLDC_2212,6T_2200KV__With_Support.IGS
CAD/brushless-motor-bldc_2212-6t-2200kv-1.snapshot.1/Motor_BLDC_2212,6T_2200KV__With_Support.SLDPRT
CAD/brushless-motor-bldc_2212-6t-2200kv-1.snapshot.1/Motor_BLDC_2212,6T_2200KV__With_Support_.SLDASM
CAD/brushless-motor-bldc_2212-6t-2200kv-1.snapshot.1/Support_2MM_Al6061_2212.IGS
CAD/brushless-motor-bldc_2212-6t-2200kv-1.snapshot.1/Support_2MM_Al6061_2212.SLDPRT
STL/Beam.STL
STL/Bearing Retainer.STL
STL/Motor Holder.STL
STL/Support.STL
STL/sensor mount.STL

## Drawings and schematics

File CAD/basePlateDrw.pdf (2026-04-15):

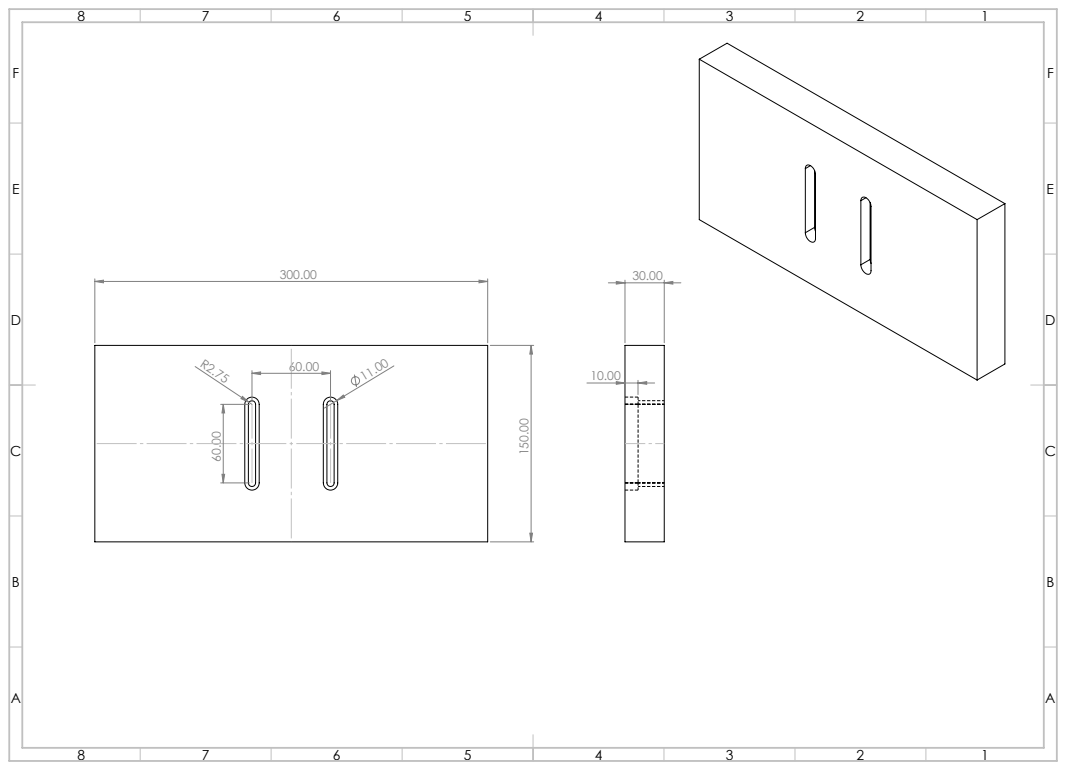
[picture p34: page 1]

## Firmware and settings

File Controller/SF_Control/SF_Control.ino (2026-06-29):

#include <Servo.h>
#include <Wire.h>
#include <avr/wdt.h>

// MPU6050
const int MPU_addr = 0x68;

int16_t AcX, AcY, AcZ, GyY;

// Angle and Angular Velocity
float theta = 0.0;        // filtered angle [deg]
float theta_acc = 0.0;    // accelerometer angle [deg]

float omega_deg = 0.0;    // gyro velocity [deg/s]
float omega = 0.0;        // gyro velocity [rad/s]

// Calibration offsets
float baseY = 0.0;
float gyroY_offset = 0.0;

// Complementary filter coefficient
float alpha = 0.99;

// Motors
const int motor1Pin = 9;
const int motor2Pin = 10;

Servo motor1;
Servo motor2;

// Timing
unsigned long lastTime = 0;
const unsigned long Ts_ms = 20;

// State Feedback Parameters
float theta_ref = 0;
float K_theta = 0.4;
float K_omega = 0.8;

// ESC Parameters

int u0 = 1100;

int u_min = 1000;
int u_max = 1300;

float pwm_slew = 6.0;
float u1_prev = 1000;
float u2_prev = 1000;

// Read MPU6050 using I2C

void readMPU()
{
  Wire.beginTransmission(MPU_addr);
  // Start reading from ACCEL_XOUT_H register
  Wire.write(0x3B);
  Wire.endTransmission(false);
  // Request 14 bytes
  Wire.requestFrom(MPU_addr, 14, true);
  // Accelerometer
  AcX = Wire.read() << 8 | Wire.read();
  AcY = Wire.read() << 8 | Wire.read();
  AcZ = Wire.read() << 8 | Wire.read();
  // Skip temperature
  Wire.read();
  Wire.read();
  // Skip GyX
  Wire.read();
  Wire.read();
  // Read GyY
  GyY = Wire.read() << 8 | Wire.read();
  // GyZ discarded automatically
}

void readSerialData()
{
  char buffer[32];

  if (Serial.available() > 0)
  {
    int len = Serial.readBytesUntil('\n',
                                    buffer,
                                    sizeof(buffer) - 1);

    buffer[len] = '\0';

    float ref, kp, kd;

    int parsed = sscanf(buffer,
                        "%f,%f,%f",
                        &ref,
                        &kp,
                        &kd);

    // Make sure ALL values received correctly
    if (parsed == 3)
    {
      // Safety limits
      if (ref >= -40.0 && ref <= 40.0)
      {
        theta_ref = ref;
      }

      if (kp >= 0.0 && kp <= 20.0)
      {
        K_theta = kp;
      }

      if (kd >= 0.0 && kd <= 20.0)
      {
        K_omega = kd;
      }
    }
  }
}

void readSerialDat()
{
    if (Serial.available() > 0)
    {
        String input = Serial.readStringUntil('\n');

        input.trim();

        // Find commas
        int firstComma  = input.indexOf(',');
        int secondComma = input.indexOf(',', firstComma + 1);

        // Validate format
        if (firstComma > 0 && secondComma > firstComma)
        {
            String refStr = input.substring(0, firstComma);

            String kpStr  = input.substring(firstComma + 1,
                                            secondComma);

            String kdStr  = input.substring(secondComma + 1);

            // Convert to float
            float ref = refStr.toFloat();
            float kp  = kpStr.toFloat();
            float kd  = kdStr.toFloat();

            // Safety limits
            if (ref >= -40 && ref <= 40)
                theta_ref = ref;

            if (kp >= 0 && kp <= 20)
                K_theta = kp;

            if (kd >= 0 && kd <= 20)
                K_omega = kd;
        }
    }
}

void setup()
{
  Serial.begin(115200);
  Wire.setWireTimeout(3000, true);
  Wire.begin();
  // Wake up MPU6050
  Wire.beginTransmission(MPU_addr);
  Wire.write(0x6B);
  Wire.write(0);
  Wire.endTransmission(true);
  delay(1000);

  // ESC Setup
  motor1.attach(motor1Pin, 1000, 2000);
  motor2.attach(motor2Pin, 1000, 2000);

  // Safe startup
  motor1.writeMicroseconds(1000);
  motor2.writeMicroseconds(1000);

  u1_prev = 1000;
  u2_prev = 1000;

  delay(5000);
  
  readMPU();

  // Initial angle reference
  baseY = atan2(AcX, AcZ) * RAD_TO_DEG;
  // Initial gyro bias
  gyroY_offset = GyY;
  // Initialize filtered angle at zero
  theta = 0.0;

  lastTime = millis();
  wdt_enable(WDTO_250MS);  // reset if loop stalls
}

void loop()
{
  wdt_reset();
  unsigned long now = millis();

  if (now - lastTime >= Ts_ms)
  {
    float dt = (now - lastTime) / 1000.0;

    // 1. Read MPU
    readMPU();
    readSerialDat();

    // 2. Accelerometer Angle
    theta_acc = atan2(AcX, AcZ) * RAD_TO_DEG - baseY;

    // 3. Gyroscope Angular Velocity
    omega_deg = -((GyY - gyroY_offset) / 131.0);

    // 4. Gyro Deadband
    if (abs(omega_deg) < 0.5)
    {
      omega_deg = 0.0;
    }

    // 5. Complementary Filter
    theta = alpha * (theta + omega_deg * dt)
          + (1.0 - alpha) * theta_acc;

    // 6. Stationary Drift Correction
    if (abs(theta_acc) < 0.5 && abs(omega_deg) < 0.03)
    {
      theta = theta_acc;
    }

    // 7. Convert omega to rad/s
    //omega = omega_deg * DEG_TO_RAD;
    static float omega_f = 0;

    omega_f = 0.9*omega_f + 0.1*omega_deg;

    omega = omega_f * DEG_TO_RAD;

    //readSerialData();

    // 8. State Feedback Control
     float du = -(K_theta * (theta - theta_ref) + K_omega * omega);

    // 9. Differential Motor Commands
    int u1 = u0 + du;
    int u2 = u0 - du;
    //kjkhigh

    // ESC saturation
    u1 = constrain(u1, u_min, u_max);
    u2 = constrain(u2, u_min, u_max);

    // 10. Slew Rate Limiting
    u1 = u1_prev + constrain(u1 - u1_prev, -pwm_slew, pwm_slew);

    u2 = u2_prev + constrain(u2 - u2_prev, -pwm_slew, pwm_slew);

    // Save previous PWM values
    u1_prev = u1;
    u2_prev = u2;

    // 11. Apply to ESCs
    motor1.writeMicroseconds((int)u1);
    motor2.writeMicroseconds((int)u2);

    // 12. Serial Logging
    static int print_cnt = 0;
    print_cnt++;
    if (print_cnt >= 10) {   // 10 Hz printing
      print_cnt = 0;
    Serial.print(theta, 2);
    Serial.print(",");

    Serial.print(omega, 2);
    Serial.print(",");

    Serial.print(u1);
    Serial.print(",");

    Serial.println(u2);
    }

    // Update Time
    lastTime = now;
  }
}
